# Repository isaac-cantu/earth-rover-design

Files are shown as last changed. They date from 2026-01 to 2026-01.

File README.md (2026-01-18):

# 🌍 Earth Rover Design

**Earth Rover Design** is a ground rover project focused on remote exploration, environmental monitoring, and teleoperation. The system integrates multiple USB cameras, environmental and distance sensors, DC motors with closed-loop control, and a distributed **client–server architecture** based on **Raspberry Pi and Arduino**.

The project was designed with modularity in mind, enabling future extensions such as autonomous navigation, SLAM, and advanced computer vision.

---

## Rover Overview



---

## System Architecture

The rover follows a distributed architecture:

* **Server (Onboard Rover)**

  * Raspberry Pi 4 (2 GB RAM)
  * Arduino Nano
  * Sensors, actuators, and cameras

* **Client (Laptop)**

  * Graphical User Interface (GUI)
  * Real-time video streaming
  * Remote motion and sensor control

### Data Flow

1. The **Raspberry Pi** acts as the main server:

   * Captures video streams from USB cameras
   * Handles network communication with the client
   * Sends control commands to the Arduino
2. The **Arduino Nano**:

   * Controls DC motors and servos
   * Reads sensor data (ToF, IMU, environmental sensors)
3. The **Client GUI**:

   * Displays live camera feeds
   * Sends movement and control commands

---

## Vision System

* **Front USB Camera**

  * Resolution: 1280×720
* **Top USB Camera**

  * Resolution: 720p
  * Field of View: 120°

Both cameras use the **UVC standard**, allowing seamless integration with Linux-based systems and OpenCV pipelines.

---

## Actuation System

* **4× DC Gear Motors**

  * Model: 25GA-370
  * Voltage: 12 V
  * Speed: 200 RPM
* **2× DRV8871 DC Motor Drivers**

  * H-Bridge configuration
  * PWM control
  * Up to 3.6 A
* **Servo Motors**

  * High-torque metal gear servo (180°)
  * SG90 micro servos for auxiliary mechanisms

---

## Sensors

* **Distance Measurement**

  * 2× VL53L0X Time-of-Flight (I2C)
* **Inertial Measurement Unit**

  * MPU-6050 (3-axis accelerometer + gyroscope)
* **Environmental Sensors**

  * DHT11 (temperature and humidity)
  * Capacitive soil moisture sensors (×3)

---

## Power System

* **12 V 5200 mAh Li-ion Battery**
* **LM2596 DC–DC Buck Converters**

  * Voltage regulation for:

    * Raspberry Pi
    * Arduino
    * Sensors
    * Servos

---

## Mechanical Design

* 3D-printed structure (**PLA**)
* **M2 and M3** screws
* 6803-2RS sealed ball bearings
* Aluminum RC chassis and suspension upgrade kit (WPL compatible)

---

## Technologies & Tools

* Raspberry Pi OS / Linux
* Arduino
* Serial communication
* USB Video (UVC)
* 3D printing
* Modular hardware design

---

## Future Improvements

* Autonomous navigation
* SLAM (visual or LiDAR-based)
* ROS integration
* Advanced computer vision with OpenCV
* Reinforcement learning for motion control
* Extended telemetry and diagnostics

---

## Suggested Repository Structure

```bash
earth-rover-design/
├── firmware/
│   └── arduino/
├── server/
│   └── raspberry_pi/
├── client/
│   └── gui/
├── cad/
│   └── stl/
├── media/
│   └── images_videos/
└── README.md
```

---

## Project Status

- Functional prototype
- Ongoing development and improvements

---

## License

This project is released under the MIT License.

---

**Regards,**
*Earth Rover Design*

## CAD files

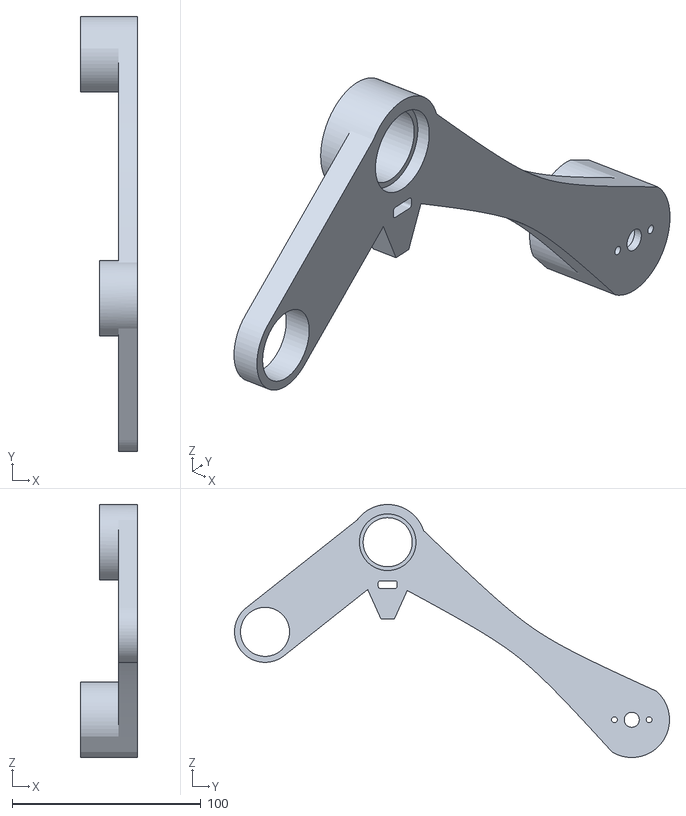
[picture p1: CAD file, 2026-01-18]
cad/Rover_Rocker_Right.stl
30.0 x 230.6 x 134.1

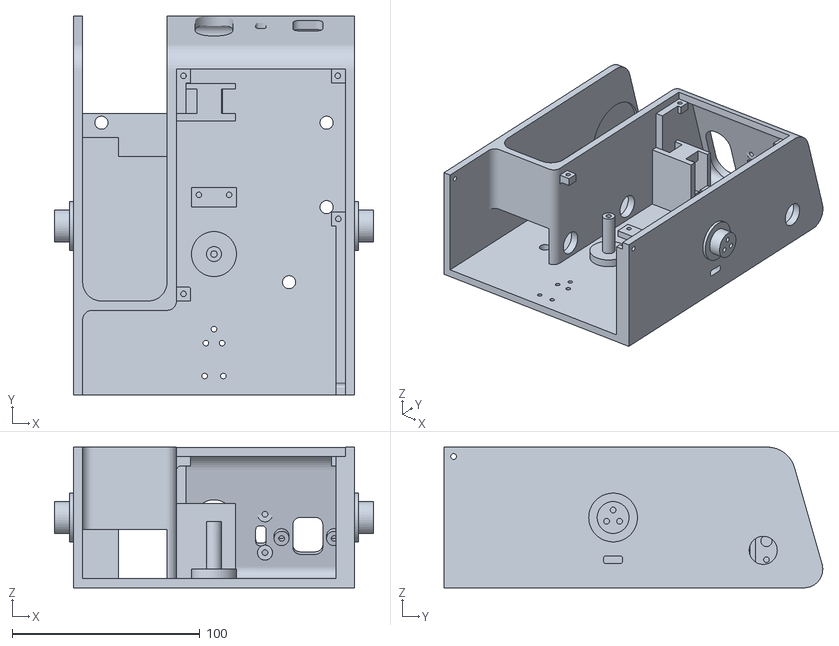
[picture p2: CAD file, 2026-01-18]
cad/Rover_Body.stl
170.0 x 201.7 x 75.0

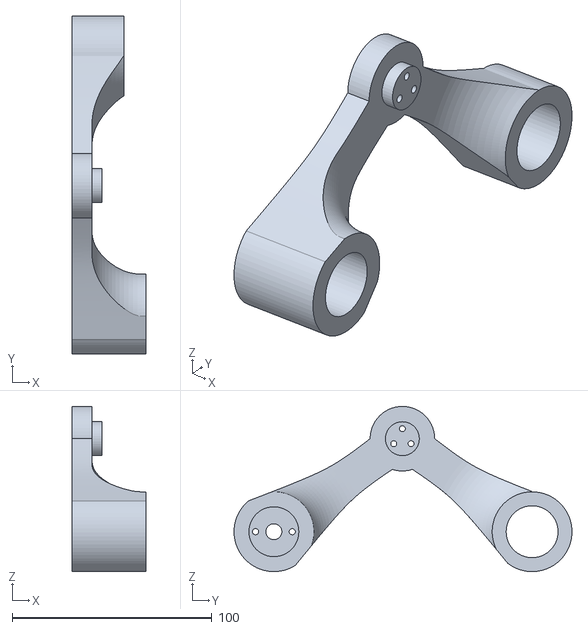
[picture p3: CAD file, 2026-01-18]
cad/Rover_Bogie_Left.stl
37.0 x 169.4 x 82.8

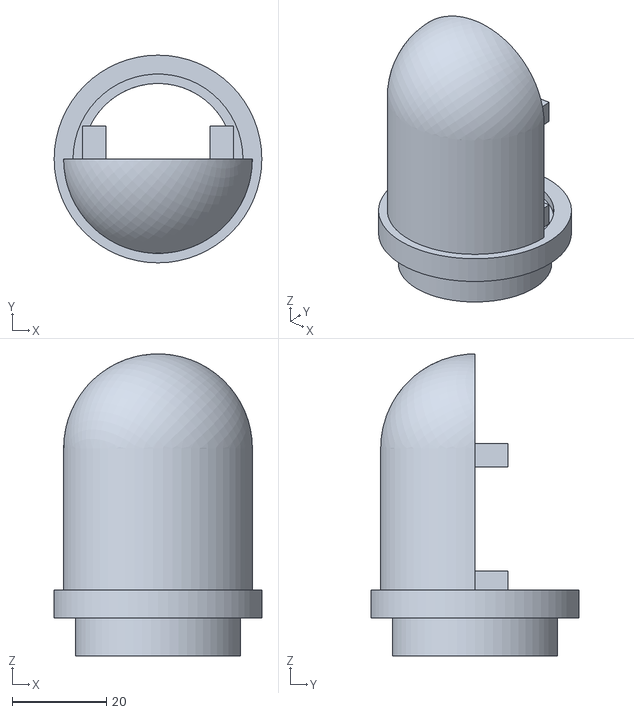
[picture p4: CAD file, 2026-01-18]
cad/Rover_Sup_Camera_Part_1.stl
44.0 x 44.0 x 64.0

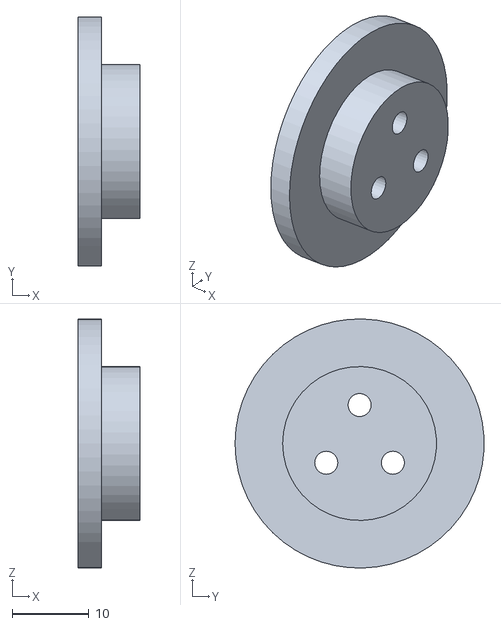
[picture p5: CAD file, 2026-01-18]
cad/Rover_Bogie_Top.stl
8.00 x 32.3 x 32.4

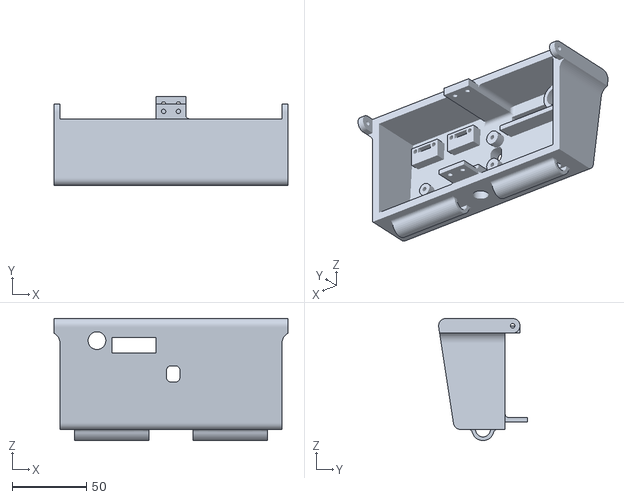
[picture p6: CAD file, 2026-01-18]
cad/Rover_Body_Back.stl
158.0 x 60.0 x 82.5

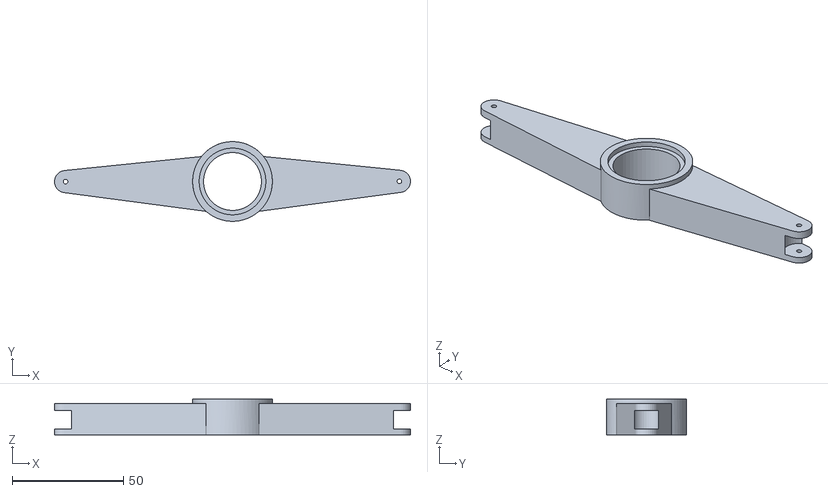
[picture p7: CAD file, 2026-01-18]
cad/Rover_Differential_Mechanism.stl
160.0 x 35.8 x 16.0

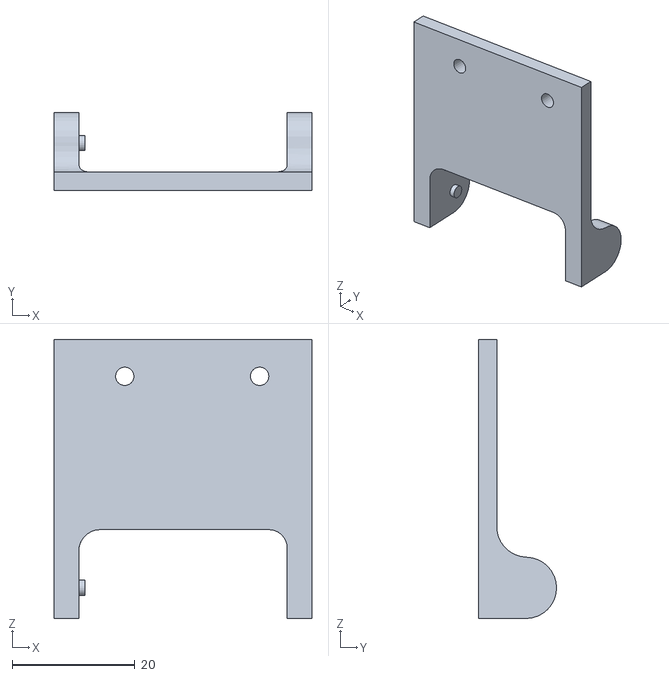
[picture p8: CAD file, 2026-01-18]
cad/Rover_Arm_Sensor_Tool.stl
42.0 x 12.7 x 45.5

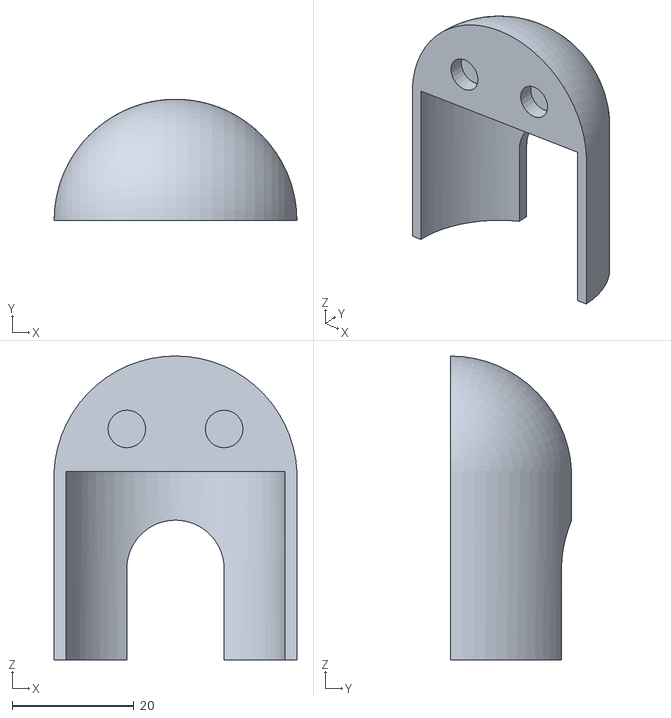
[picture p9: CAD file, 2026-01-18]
cad/Rover_Sup_Camera_Part_2.stl
39.9 x 20.0 x 50.0

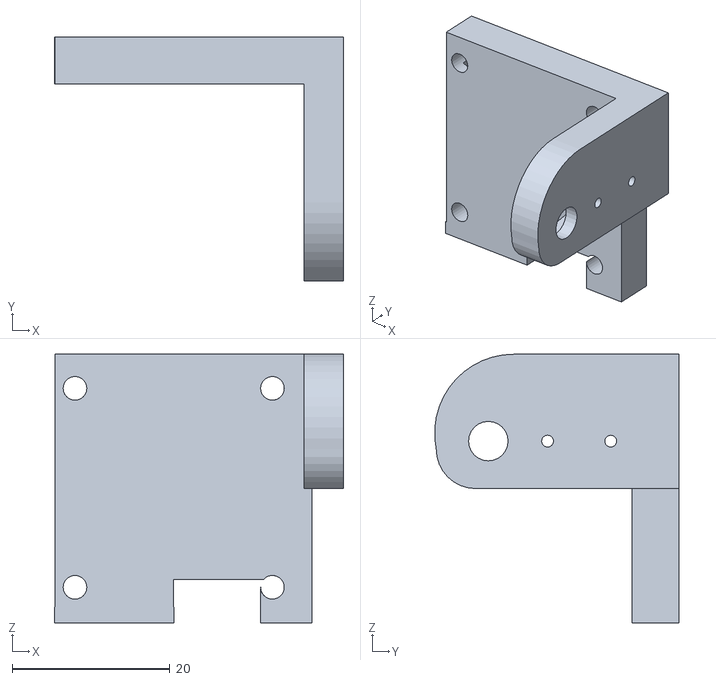
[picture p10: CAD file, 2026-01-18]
cad/Rover_Front_Camera.stl
36.6 x 31.0 x 34.0

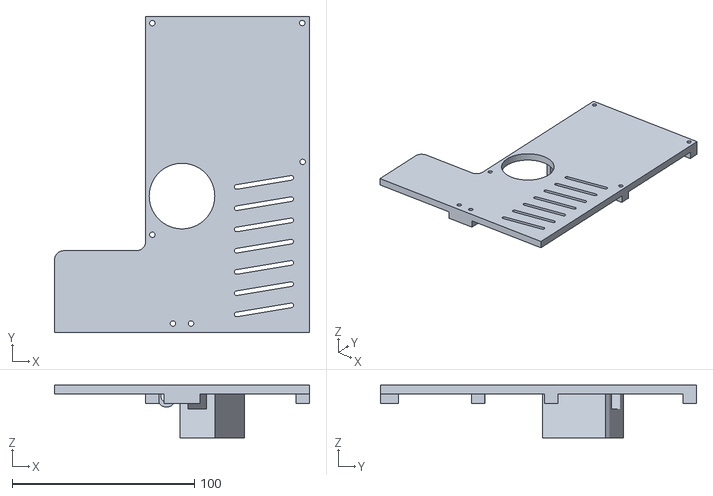
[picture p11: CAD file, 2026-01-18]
cad/Rover_Body_Cover.stl
140.0 x 173.7 x 29.0

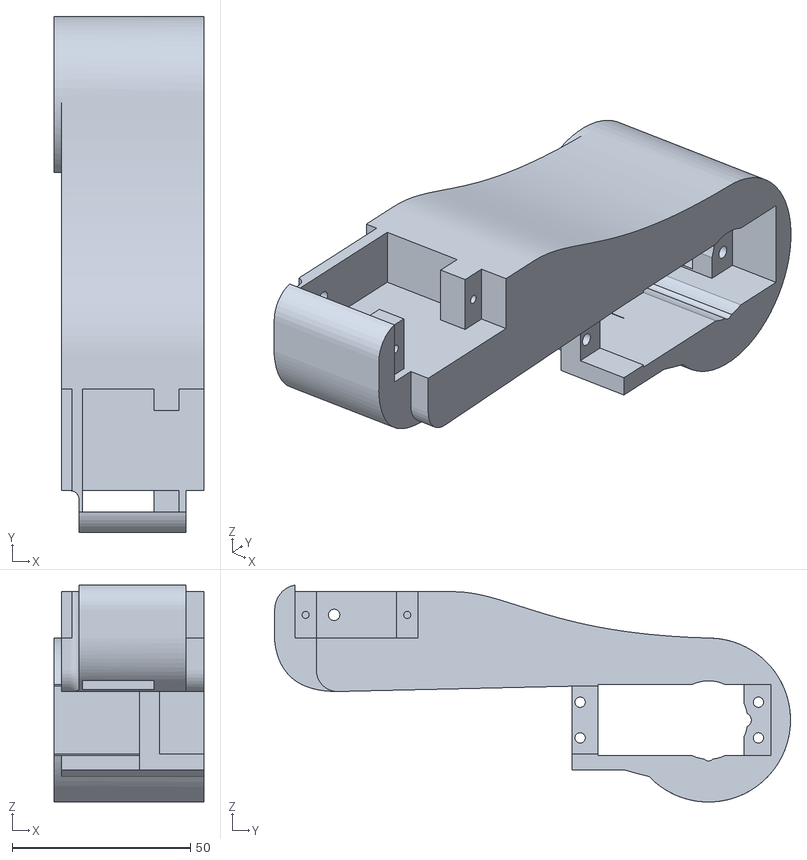
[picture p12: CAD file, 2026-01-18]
cad/Rover_Arm_Base.stl
42.0 x 144.7 x 60.9

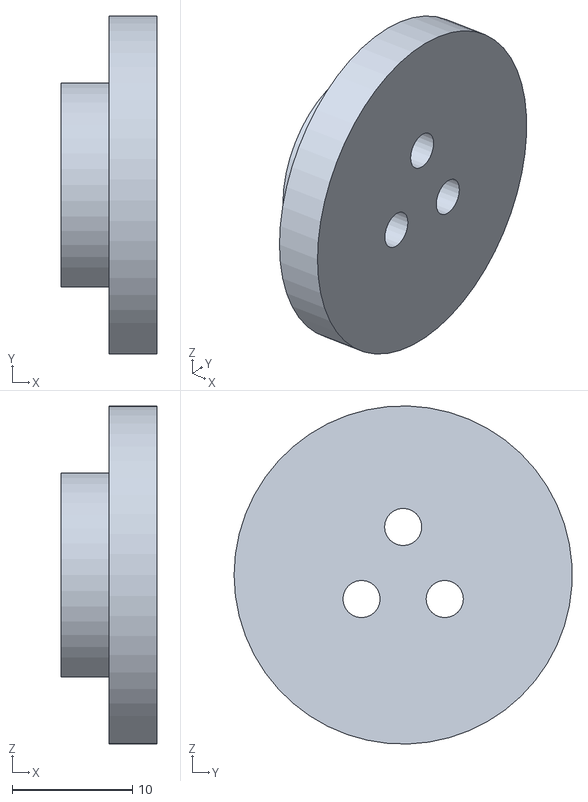
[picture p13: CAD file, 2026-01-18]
cad/Rover_Rocker_Top.stl
8.00 x 28.1 x 28.1

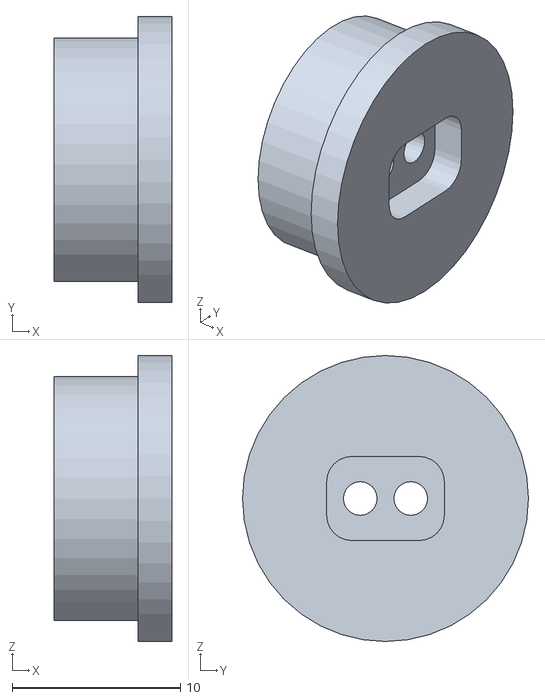
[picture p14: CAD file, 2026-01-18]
cad/Rover_Body_Right_Sensor.stl
7.00 x 17.0 x 17.0

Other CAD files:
cad/Rover_Bogie_Right.stl
cad/Rover_Rocker_Left.stl
cad/Rover_Wheel.stl
cad/Rover_Joint.stl
cad/Rover_Wheel_Top.stl

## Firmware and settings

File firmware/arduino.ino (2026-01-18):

#include <Servo.h>
#include <dht.h>
//#include <Adafruit_VL53L0X.h>
#include <Wire.h>
#include <MPU6050.h>

// =====================================================
// SERVOS
// =====================================================
Servo servo1;  // Codo brazo (0-180°)
Servo servo2;  // Sensor brazo (0-180°)
Servo servo3;  // Cámara frontal (0-30°)
//Servo servo4;  // Cámara superior (0-180°)

// =====================================================
// SENSORES
// =====================================================
dht DHT;
//Adafruit_VL53L0X lox = Adafruit_VL53L0X();
MPU6050 mpu;

const int PIN_TEMP = 8;
const int PIN_HUMEDAD = A0;
const int PIN_LUZ = A1;

// =====================================================
// MOTORES DC (PWM)
// =====================================================
// Motor A = Izquierdo
const int MOTOR_A1 = 3;   // Adelante
const int MOTOR_A2 = 5;   // Atrás
// Motor B = Derecho
const int MOTOR_B1 = 11;  // Adelante
const int MOTOR_B2 = 6;  // Atrás

// =====================================================
// CALIBRACIÓN DE MOTORES
// =====================================================
// Factor de corrección para compensar el drift
// Si el rover va a la izquierda, el motor derecho es más débil
// Ajusta estos valores según tu robot:
// - Si va mucho a la izquierda: aumenta FACTOR_DERECHO o disminuye FACTOR_IZQUIERDO
// - Si va mucho a la derecha: aumenta FACTOR_IZQUIERDO o disminuye FACTOR_DERECHO
float FACTOR_IZQUIERDO = 0.95;  // Reduce ligeramente el motor izquierdo
float FACTOR_DERECHO = 1.0;     // Motor derecho al 100%

// Velocidad mínima para que los motores se muevan
const int VEL_MINIMA = 50;

// =====================================================
// VARIABLES MPU6050
// =====================================================
int16_t ax, ay, az;
int16_t gx, gy, gz;

// =====================================================
// SETUP
// =====================================================
void setup() {
  Serial.begin(9600);
  
  // Inicializar servos
  servo1.attach(4);
  servo2.attach(2);
  servo3.attach(7);
  //servo4.attach(9);
  
  // Posiciones iniciales
  servo1.write(0);
  servo2.write(0);
  servo3.write(15);
  //servo4.write(90);
  
  // Configurar pines de motores
  pinMode(MOTOR_A1, OUTPUT);
  pinMode(MOTOR_A2, OUTPUT);
  pinMode(MOTOR_B1, OUTPUT);
  pinMode(MOTOR_B2, OUTPUT);
  
  // Detener motores
  detenerMotores();
  
  // Inicializar MPU6050
  Wire.begin();
  mpu.initialize();
  
  if (mpu.testConnection()) {
    Serial.println("MPU6050: OK");
  } else {
    Serial.println("MPU6050: ERROR");
  }
  
  // Inicializar VL53L0X
  //if (!lox.begin()) {
  //  Serial.println("VL53L0X: ERROR");
  //} else {
  //  Serial.println("VL53L0X: OK");
  //}
  
  Serial.println("ARDUINO LISTO");
  Serial.print("Calibracion: IZQ=");
  Serial.print(FACTOR_IZQUIERDO);
  Serial.print(" DER=");
  Serial.println(FACTOR_DERECHO);
  delay(500);
}

// =====================================================
// FUNCIONES DE MOTORES - MEJORADAS CON CALIBRACIÓN
// =====================================================

void detenerMotores() {
  // Apagar todos los pines
  analogWrite(MOTOR_A1, 0);
  analogWrite(MOTOR_A2, 0);
  analogWrite(MOTOR_B1, 0);
  analogWrite(MOTOR_B2, 0);
}

void avanzar(int vel) {
  vel = constrain(vel, VEL_MINIMA, 255);
  
  // Aplicar factores de calibración
  int vel_izq = (int)(vel * FACTOR_IZQUIERDO);
  int vel_der = (int)(vel * FACTOR_DERECHO);
  
  // Asegurar que no excedan límites
  vel_izq = constrain(vel_izq, VEL_MINIMA, 255);
  vel_der = constrain(vel_der, VEL_MINIMA, 255);
  
  // Ambos motores adelante
  analogWrite(MOTOR_A1, vel_izq);  // Izquierdo adelante
  analogWrite(MOTOR_A2, 0);
  analogWrite(MOTOR_B1, vel_der);  // Derecho adelante
  analogWrite(MOTOR_B2, 0);
}

void retroceder(int vel) {
  vel = constrain(vel, VEL_MINIMA, 255);
  
  // Aplicar factores de calibración
  int vel_izq = (int)(vel * FACTOR_IZQUIERDO);
  int vel_der = (int)(vel * FACTOR_DERECHO);
  
  vel_izq = constrain(vel_izq, VEL_MINIMA, 255);
  vel_der = constrain(vel_der, VEL_MINIMA, 255);
  
  // Ambos motores atrás
  analogWrite(MOTOR_A1, 0);
  analogWrite(MOTOR_A2, vel_izq);  // Izquierdo atrás
  analogWrite(MOTOR_B1, 0);
  analogWrite(MOTOR_B2, vel_der);  // Derecho atrás
}

void girarIzquierda(int vel) {
  vel = constrain(vel, VEL_MINIMA, 255);
  
  // En giros, usar velocidad completa sin calibración
  // porque queremos máximo torque de giro
  
  // Izquierdo atrás, Derecho adelante (giro en el lugar)
  analogWrite(MOTOR_A1, 0);
  analogWrite(MOTOR_A2, vel);  // Izquierdo atrás
  analogWrite(MOTOR_B1, vel);  // Derecho adelante
  analogWrite(MOTOR_B2, 0);
}

void girarDerecha(int vel) {
  vel = constrain(vel, VEL_MINIMA, 255);
  
  // En giros, usar velocidad completa sin calibración
  
  // Izquierdo adelante, Derecho atrás (giro en el lugar)
  analogWrite(MOTOR_A1, vel);  // Izquierdo adelante
  analogWrite(MOTOR_A2, 0);
  analogWrite(MOTOR_B1, 0);
  analogWrite(MOTOR_B2, vel);  // Derecho atrás
}

// =====================================================
// FUNCIÓN PARA AJUSTAR CALIBRACIÓN EN TIEMPO REAL
// =====================================================
void ajustarCalibracion(float factor_izq, float factor_der) {
  FACTOR_IZQUIERDO = constrain(factor_izq, 0.5, 1.5);
  FACTOR_DERECHO = constrain(factor_der, 0.5, 1.5);
  
  Serial.print("Nueva calibracion: IZQ=");
  Serial.print(FACTOR_IZQUIERDO);
  Serial.print(" DER=");
  Serial.println(FACTOR_DERECHO);
}

// =====================================================
// FUNCIONES DE SENSORES
// =====================================================

float leerTemperatura() {
  int chk = DHT.read11(PIN_TEMP);
  if (chk == DHTLIB_OK) {
    return DHT.temperature;
  }
  return -999;
}

int leerHumedad() {
  int lectura = analogRead(PIN_HUMEDAD);
  // Calibración: 588 = 0%, 308 = 100%
  int humedad = map(lectura, 588, 308, 0, 100);
  return constrain(humedad, 0, 100);
}

int leerLuz() {
  int lectura = analogRead(PIN_LUZ);
  // 1023 = oscuro, 0 = brillante
  int luz = map(lectura, 1023, 0, 0, 100);
  return constrain(luz, 0, 100);
}

float leerDistancia() {
  //VL53L0X_RangingMeasurementData_t medida;
  //lox.rangingTest(&medida, false);
  
  //if (medida.RangeStatus != 4) {
  //  return medida.RangeMilliMeter;
  //}
  return -1;
}

void leerMPU() {
  mpu.getMotion6(&ax, &ay, &az, &gx, &gy, &gz);
}

// =====================================================
// PROCESAMIENTO DE COMANDOS
// =====================================================

void procesarComando(String comando) {
  comando.trim();
  
  int espacio = comando.indexOf(' ');
  String accion;
  int valor = 0;
  
  if (espacio > 0) {
    accion = comando.substring(0, espacio);
    valor = comando.substring(espacio + 1).toInt();
  } else {
    accion = comando;
  }
  
  // ========== MOVIMIENTO ==========
  if (accion == "avanzar") {
    avanzar(valor > 0 ? valor : 200);
    Serial.println("OK: Avanzando");
  }
  else if (accion == "retroceder") {
    retroceder(valor > 0 ? valor : 200);
    Serial.println("OK: Retrocediendo");
  }
  else if (accion == "izquierda") {
    girarIzquierda(valor > 0 ? valor : 200);
    Serial.println("OK: Girando izquierda");
  }
  else if (accion == "derecha") {
    girarDerecha(valor > 0 ? valor : 200);
    Serial.println("OK: Girando derecha");
  }
  else if (accion == "stop") {
    detenerMotores();
    Serial.println("OK: Detenido");
  }
  
  // ========== CALIBRACIÓN DE MOTORES ==========
  else if (accion == "calibrar") {
    // Comando: calibrar 0.95 1.0
    // Formato: calibrar <factor_izq> <factor_der>
    int segundoEspacio = comando.indexOf(' ', espacio + 1);
    if (segundoEspacio > 0) {
      float factor_izq = comando.substring(espacio + 1, segundoEspacio).toFloat();
      float factor_der = comando.substring(segundoEspacio + 1).toFloat();
      ajustarCalibracion(factor_izq, factor_der);
    } else {
      Serial.println("Uso: calibrar <factor_izq> <factor_der>");
      Serial.println("Ejemplo: calibrar 0.95 1.0");
    }
  }
  else if (accion == "get_calibracion") {
    Serial.print("Calibracion actual: IZQ=");
    Serial.print(FACTOR_IZQUIERDO);
    Serial.print(" DER=");
    Serial.println(FACTOR_DERECHO);
  }
  
  // ========== SERVOS ==========
  else if (accion == "servo1") {
    valor = constrain(valor, 0, 180);
    servo1.write(valor);
    Serial.print("Servo1: ");
    Serial.print(valor);
    Serial.println("°");
  }
  else if (accion == "servo2") {
    valor = constrain(valor, 0, 180);
    servo2.write(valor);
    Serial.print("Servo2: ");
    Serial.print(valor);
    Serial.println("°");
  }
  else if (accion == "servo3") {
    valor = constrain(valor, 0, 30);
    servo3.write(valor);
    Serial.print("Servo3: ");
    Serial.print(0);
    Serial.println("°");
  }
  else if (accion == "servo4") {
  //  valor = constrain(valor, 0, 180);
  //  servo4.write(valor);
    Serial.print("Servo4: ");
    Serial.print(0);
    Serial.println("°");
  }
  
  // ========== SENSORES ==========
  else if (accion == "temp") {
    float temp = leerTemperatura();
    if (temp > -999) {
      Serial.print(temp, 1);
      Serial.println(" °C");
    } else {
      Serial.println("Error DHT");
    }
  }
  else if (accion == "humedad") {
    int hum = leerHumedad();
    Serial.print(hum);
    Serial.println(" %");
  }
  else if (accion == "luz") {
    int luz = leerLuz();
    Serial.print(luz);
    Serial.println(" V");
  }
  else if (accion == "dist") {
    float dist = leerDistancia();
    if (dist > 0) {
      Serial.print(dist, 0);
      Serial.println(" mm");
    } else {
      Serial.println("Fuera de rango");
    }
  }
  else if (accion == "mpu") {
    leerMPU();
    Serial.print("AX: "); Serial.print(ax);
    Serial.print(" AY: "); Serial.print(ay);
    Serial.print(" AZ: "); Serial.print(az);
    Serial.print(" GX: "); Serial.print(gx);
    Serial.print(" GY: "); Serial.print(gy);
    Serial.print(" GZ: "); Serial.println(gz);
  }
  
  // ========== DIAGNÓSTICO ==========
  else if (accion == "status") {
    Serial.println("=== STATUS ===");
    Serial.print("Temp: "); Serial.print(leerTemperatura()); Serial.println(" C");
    Serial.print("Luz: "); Serial.print(leerLuz()); Serial.println(" V");
    Serial.print("Humedad: "); Serial.print(leerHumedad()); Serial.println(" %");
    Serial.print("Dist: "); Serial.print(leerDistancia()); Serial.println(" mm");
    Serial.print("Calibracion: IZQ="); Serial.print(FACTOR_IZQUIERDO);
    Serial.print(" DER="); Serial.println(FACTOR_DERECHO);
  }
  
  // ========== TEST MOTORES CON CALIBRACIÓN ==========
  else if (accion == "test_motores") {
    Serial.println("=== TEST DE MOTORES ===");
    
    Serial.println("Avanzar 3s...");
    avanzar(150);
    delay(3000);
    detenerMotores();
    delay(1000);
    
    Serial.println("Retroceder 3s...");
    retroceder(150);
    delay(3000);
    detenerMotores();
    delay(1000);
    
    Serial.println("Izquierda 2s...");
    girarIzquierda(150);
    delay(2000);
    detenerMotores();
    delay(1000);
    
    Serial.println("Derecha 2s...");
    girarDerecha(150);
    delay(2000);
    detenerMotores();
    
    Serial.println("Test completado");
    Serial.println("Si el robot se desvio, ajusta calibracion con:");
    Serial.println("  calibrar <factor_izq> <factor_der>");
  }
  
  // ========== COMANDO DESCONOCIDO ==========
  else {
    Serial.print("ERROR: Comando desconocido: ");
    Serial.println(comando);
  }
}

// =====================================================
// LOOP PRINCIPAL
// =====================================================
void loop() {
  if (Serial.available() > 0) {
    String comando = Serial.readStringUntil('\n');
    procesarComando(comando);
  }
  
  delay(10);
}

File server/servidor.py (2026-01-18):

# servidor_completo.py - Servidor mejorado con requisitos específicos
import socket
import threading
import struct
import time
import cv2
import serial
import csv
import os
import json
from queue import Queue, Empty
from datetime import datetime
import glob
import numpy as np

# ==================== CONFIGURACIÓN ====================
def detectar_puerto_arduino():
    posibles = glob.glob('/dev/ttyUSB*') + glob.glob('/dev/ttyACM*')
    if posibles:
        print(f"[INFO] Puertos Arduino detectados: {posibles}")
        return posibles[0]
    print("[WARN] No se detectó puerto Arduino automáticamente")
    return None

ARDUINO_PORT = detectar_puerto_arduino() or '/dev/ttyUSB0'
BAUD_RATE = 9600
BUFFER_SIZE = 4096
SERVER_IP = '0.0.0.0'
UDP_PORT = 50000
TCP_PORT_VIDEO_FRONTAL = 50001
TCP_PORT_VIDEO_SUPERIOR = 50002
TCP_PORT_STATUS = 50003

# Configuración de cámaras
CAMERA_FRONTAL = 0
CAMERA_SUPERIOR = 1

# Directorios
os.makedirs("capturas", exist_ok=True)
os.makedirs("logs", exist_ok=True)

# ==================== VARIABLES GLOBALES ====================
ser = None
csv_lock = threading.Lock()
imagen_lock = threading.Lock()
estado_rover = {
    "temperatura": "N/A",
    "humedad": "N/A",
    "luz": "N/A",
    "distancia": "N/A",
    "accel": {"x": 0, "y": 0, "z": 0},
    "gyro": {"x": 0, "y": 0, "z": 0},
    "marcadores_detectados": 0,
    "modo": "manual",
    "brazo_activo": False,
    "velocidad_actual": 200,
    "ultimo_log": "Sistema iniciado",
    "camara_frontal_activa": False,
    "camara_superior_activa": False,
    "calibracion_motores": {"izquierdo": 0.95, "derecho": 1.0}
}
estado_lock = threading.Lock()

frame_frontal_actual = None
frame_superior_actual = None

serial_queue = Queue()

# ==================== INICIALIZAR ARDUINO ====================
def conectar_arduino():
    global ser
    try:
        ser = serial.Serial(ARDUINO_PORT, BAUD_RATE, timeout=1)
        time.sleep(2)
        print(f"[SERVIDOR] Arduino conectado en {ARDUINO_PORT}")
        agregar_log("Arduino conectado correctamente")
        return True
    except Exception as e:
        print(f"[ERROR] No se pudo conectar al Arduino: {e}")
        agregar_log(f"Error conectando Arduino: {e}")
        return False

# ==================== GESTIÓN DE LOGS ====================
def agregar_log(mensaje):
    """Agrega un log con timestamp"""
    timestamp = datetime.now().strftime("%H:%M:%S")
    log_mensaje = f"[{timestamp}] {mensaje}"
    with estado_lock:
        estado_rover["ultimo_log"] = log_mensaje
    print(f"[LOG] {log_mensaje}")
    
    try:
        with open("logs/servidor_logs.txt", "a") as f:
            f.write(log_mensaje + "\n")
    except:
        pass

# ==================== COMUNICACIÓN SERIAL ====================
def serial_worker():
    """Worker thread para comandos seriales"""
    while True:
        try:
            comando, callback = serial_queue.get(timeout=0.1)
            if comando is None:
                break
            
            respuesta = enviar_a_arduino_directo(comando)
            if callback:
                callback(respuesta)
            
            serial_queue.task_done()
        except Empty:
            continue
        except Exception as e:
            print(f"[ERROR SERIAL] {e}")

def enviar_a_arduino_async(comando, callback=None):
    """Envía comando de forma asíncrona"""
    serial_queue.put((comando, callback))

def enviar_a_arduino_directo(comando, espera_respuesta=True, timeout=1.0):
    """Envía comando directamente al Arduino"""
    if ser is None or not ser.is_open:
        return "Arduino no disponible"
    
    try:
        ser.reset_input_buffer()
        ser.write((comando + '\n').encode())
        
        if espera_respuesta:
            deadline = time.time() + timeout
            while time.time() < deadline:
                if ser.in_waiting > 0:
                    line = ser.readline().decode(errors='ignore').strip()
                    if line:
                        return line
                time.sleep(0.01)
            return "Sin respuesta del Arduino"
        return "Comando enviado"
    except Exception as e:
        return f"Error serial: {e}"

# ==================== ACTUALIZACIÓN DE SENSORES ====================
def actualizar_sensores_thread():
    """Thread que actualiza sensores cada 0.5 segundos"""
    while True:
        try:
            temp = enviar_a_arduino_directo("temp", timeout=0.5)
            with estado_lock:
                estado_rover["temperatura"] = temp
            
            humedad = enviar_a_arduino_directo("humedad", timeout=0.5)
            with estado_lock:
                estado_rover["humedad"] = humedad
            
            luz = enviar_a_arduino_directo("luz", timeout=0.5)
            with estado_lock:
                estado_rover["luz"] = luz
            
            dist = enviar_a_arduino_directo("dist", timeout=0.5)
            with estado_lock:
                estado_rover["distancia"] = dist
            
            mpu_data = enviar_a_arduino_directo("mpu", timeout=0.5)
            try:
                partes = mpu_data.split()
                if len(partes) >= 12:
                    with estado_lock:
                        estado_rover["accel"]["x"] = partes[1]
                        estado_rover["accel"]["y"] = partes[3]
                        estado_rover["accel"]["z"] = partes[5]
                        estado_rover["gyro"]["x"] = partes[7]
                        estado_rover["gyro"]["y"] = partes[9]
                        estado_rover["gyro"]["z"] = partes[11]
            except:
                pass
            
            time.sleep(0.5)
            
        except Exception as e:
            print(f"[ERROR SENSORES] {e}")
            time.sleep(1)

# ==================== GUARDADO DE DATOS ====================
def inicializar_csv():
    """Crea archivo CSV con encabezados específicos requeridos"""
    archivo = "datos_exploracion.csv"
    if not os.path.exists(archivo):
        with csv_lock:
            with open(archivo, mode='w', newline='') as f:
                writer = csv.writer(f)
                # Encabezados según requerimientos
                writer.writerow([
                    "TIMESTAMP",
                    "PIXELSU", 
                    "PIXELSV", 
                    "TIPO_MARCADOR", 
                    "INTENSIDAD_LUZ", 
                    "TEMPERATURA", 
                    "HUMEDAD"
                ])
    return archivo
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
